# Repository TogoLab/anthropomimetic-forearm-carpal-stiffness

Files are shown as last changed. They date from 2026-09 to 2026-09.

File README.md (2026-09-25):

# Anthropomimetic Soft Robotic Forearm with Independently Articulated Carpal Bones

🌍 English (this page)  
📘 [Japanese](./README_JP.md)

---

## Overview

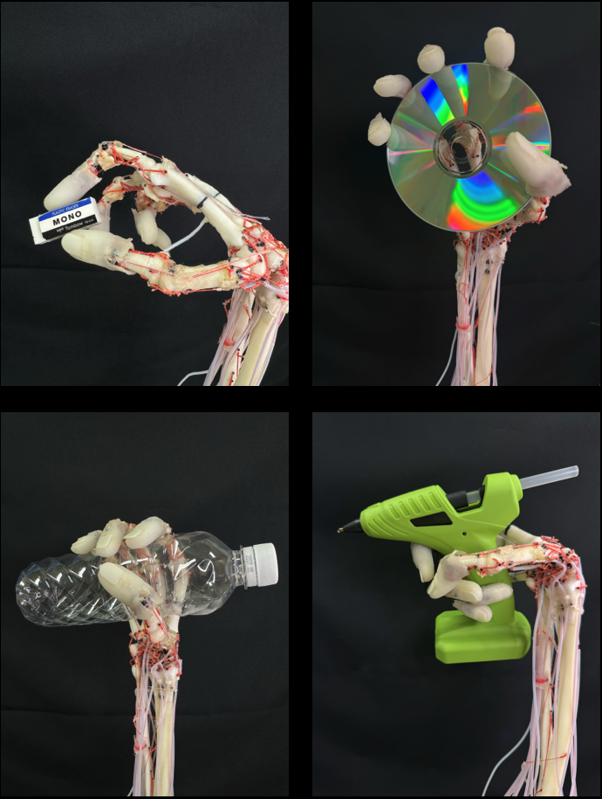
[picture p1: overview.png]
Anthropomimetic Soft Robotic Forearm


This repository provides open-hardware data for an **anatomically accurate anthropomimetic soft robotic forearm** composed of eight independently movable carpal bones interconnected by ligaments, 22 actuated muscles, and compliant fingertips, together with the CAD data of the assembly and experimental jigs, the muscle control firmware, and the wrist-stiffness / carpal-motion analysis code. The purpose of this repository is to improve the reproducibility of the following paper.

Yoshinobu Obata, Yinlai Jiang, Hiroshi Yokoi, and Shunta Togo.  
“Anthropomimetic Soft Robotic Forearm with Independently Articulated Carpal Bones Enabling Human-Like Adaptive Stiffness Modulability.”  
arXiv:2609.29176 [cs.RO], 2026.  
https://doi.org/10.48550/arXiv.2609.29176

---

## Repository Structure

```
analysis/   Wrist stiffness ellipse fitting and carpal motion analysis code with measured data, Python
firmware/   Muscle (Dynamixel) control firmware for the robotic forearm, PlatformIO
cad/        CAD files of the forearm and the experimental/assembly jigs (STEP, F3D)
stl/        STL files for 3D printing (bones, fingertip molds, TFCC, motor tower and pulleys, assembly and experimental jigs)
media/      Supplementary video
licenses/   Full text of the applicable licenses (CC BY 4.0, CC BY-SA 2.1 JP)
```

---

## Bill of Materials (BOM)

- [Bill of Materials (BOM)](./BOM.md)

---

## License

Multiple licenses apply to different parts of this repository.  
The bone models and fingertip molds are derived from **BodyParts3D** (Life Science Integrated Database Center) and are distributed under **CC BY-SA 2.1 JP**; all other materials are original works by the authors and are distributed under **CC BY 4.0**.  
Please make sure to check the license associated with each file before use.  
For details, see `LICENSE.txt` and the contents of the `licenses/` directory.

---

## Notes and Disclaimer

- This data is provided for educational and research purposes.
- Use, modification, and redistribution are performed at your own risk.
- The authors and affiliated institutions assume no responsibility for any damage or loss resulting from the use of this repository.

---

## Author and Contact

Shunta Togo  
Associate Professor  
Department of Mechanical and Intelligent Systems Engineering  
Graduate School of Informatics and Engineering  
The University of Electro-Communications  

- [ResearchMap](https://researchmap.jp/shuntatogo?lang=en)  
- [Togo Laboratory](http://www.hi.mce.uec.ac.jp/togolab/)  
- [X (Twitter)](https://twitter.com/togo_lab/)  
- [Instagram](https://www.instagram.com/togolab_uec/)  
- [YouTube](https://www.youtube.com/channel/UC10spcvW8-pCTLKy5rrDHyw)

For questions or bug reports, please use GitHub Issues or contact:  
s.togo[at]uec.ac.jp

Support for educational and research activities at the Togo Laboratory is also welcome.  
- https://www.uec.ac.jp/kikin/archives/fund/togolab

---

## Related Publications

* Yoshinobu Obata, Yinlai Jiang, Hiroshi Yokoi and Shunta Togo, "Design of anthropomimetic robotic wrist joint and forearm," 2023 IEEE International Conference on Systems, Man, and Cybernetics (SMC), pp. 1766–1771, Oahu, Hawaii, USA, Oct. 1–4, 2023.

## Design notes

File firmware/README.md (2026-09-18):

# 人体模倣前腕ロボットの制御システム

DynamixelサーボモーターとTeensy 4.1マイクロコントローラーを使用した22アクチュエーター人体模倣前腕ロボットの包括的制御システム。

## 概要

このプロジェクトは、人間の手と前腕の筋肉構造を模倣した前腕ロボットの高度な制御システムを実装しています。システムは22個の個別のDynamixelサーボモーターを制御し、それぞれが異なる筋肉を表現し、位置制御、電流制御、ハイブリッド電流ベース位置制御など、さまざまな動作モードをサポートしています。

## 必要なハードウェア

### マイクロコントローラー
- **Teensy 4.1**（SDIOと十分なI/Oのために必要）

### サーボモーター
- **22個のDynamixelサーボモーター**（プロトコル2.0対応）
- Dynamixel通信インターフェース（Serial2、ピン7-8）
- 方向制御ピン（ピン2）

### ストレージ
- **SDカード**（Teensy 4.1内蔵SDIOを使用）

### 追加コンポーネント
- 力量計センサー（アナログピンA16）
- 外部同期信号入力（ピンA17）
- PWMサーボ出力（ピン9）補助アクチュエーター用
- シリアルディスプレイとデバッグインターフェース

## ソフトウェア依存関係

### PlatformIOライブラリ
- `robotis-git/Dynamixel2Arduino@^0.6.3`
- `TeensyThreads`（マルチスレッド用）
- `SdFat`（SDカード操作）
- `Servo`（PWMサーボ制御）

## プロジェクト構造

```
├── src/
│   ├── main.cpp           # メインプログラムループとコマンドインターフェース
│   ├── contorol.h         # コアモーター制御機能
│   ├── DXLSetup.h         # Dynamixel設定と通信
│   ├── muscle.h           # 筋肉オブジェクト定義と管理
│   ├── motion.h           # モーション制御アルゴリズム
│   ├── coop_graph.h       # 協調筋グラフ（手首⇔指/屈伸の伝播）
│   ├── SDContorol.h       # SDカードデータ管理
│   ├── tests.h            # テストと校正機能
│   ├── teaching.h         # 教示モード（ユーザが手動で姿勢を作り SDに記録）
│   ├── config.h           # タイミング・ピン・サーボ数などのコンパイル時定数
│   ├── muscle_specs.h     # 筋ごとの静的属性（電流リミット・姿勢・可動域）テーブル
│   └── logging.h          # CSVヘッダー出力などのロギング補助
├── platformio.ini         # PlatformIO設定
└── README.md              # このファイル
```

## 筋肉マッピング

システムは以下の筋肉を表現する22個のサーボモーターを制御します：

### 指筋肉（0-14）
- **IndexFDP**（0）：示指深指屈筋
- **MiddleFDP**（1）：中指深指屈筋
- **MiddleFDS**（2）：中指浅指屈筋
- **RingFDP**（3）：薬指深指屈筋
- **PinkyFDP**（4）：小指深指屈筋
- **FPL**（5）：長母指屈筋
- **APM**（6）：母指内転筋（無限巻取り機構）
- **OPM**（7）：母指対立筋
- **APB**（8）：短母指外転筋
- **EIP**（9）：示指伸筋
- **EDM**（10）：小指伸筋
- **ED**（11）：総指伸筋
- **EPB**（12）：短母指伸筋
- **EPL**（13）：長母指伸筋
- **APL**（14）：長母指外転筋

### 手首筋肉（15-21）
- **FCR**（15）：橈側手根屈筋
- **FCU**（16）：尺側手根屈筋
- **ECRL**（17）：長橈側手根伸筋
- **ECU**（18）：尺側手根伸筋
- **SPN**（19）：回外筋（無限巻取り機構）
- **BPB**（20）：上腕二頭筋
- **PT**（21）：円回内筋

## 制御モード

### 1. 電流ベース位置制御（デフォルト）
- 位置制御と電流制御を組み合わせ
- 位置目標を持つコンプライアントモーションを可能にする

### 2. 純粋電流制御
- 直接電流・トルク制御
- 共収縮と剛性制御に使用

### 3. 位置制御
- 従来の位置のみ制御
- 精密な位置決めに使用

## 使用方法

### 初期設定

1. **ファームウェアの書き込み：**
   ```bash
   pio run --target upload
   ```

2. **シリアルモニターに接続：**
   ```bash
   pio device monitor
   ```

3. **システムの初期化：**
   - システムは自動的にDynamixel通信を初期化
   - モーション保存用のSDカードが初期化される

### 利用可能なコマンド

#### 教示モード
```
Teach
```
- 新しいモーションを記録する教示モードに入る
- 手を手動で位置決めし、ウェイポイントを保存
- 無限巻取り機構の使用をサポート（y/nプロンプト）

#### モーション再生
```
Start
```
- SDカードから記録されたモーションを再生
- 反復回数を選択
- モーションタイプを選択（1: リラックス、2: 把握）

#### システム制御
```
Relax    # 全モーターのトルクを無効化
Fix      # 低電流保持を有効化
Show     # 現在のサーボ位置を表示
```

#### ファイル管理
```
ls       # SDカード上のファイル一覧表示
Delete   # 保存されたモーションファイルを削除
```

#### テストと校正
```
Static   # 関節剛性テスト（4モード）
Random   # ランダム筋肉活動テスト
Unit     # 個別筋肉ユニットテスト
FingerDrive  # 個別指駆動テスト
```

#### マニュアル制御
```
Manual   # マニュアル位置入力（22個のカンマ区切り値）
servo    # 補助PWMサーボテスト（0-100%）
```

### モーションタイプ

#### 把握モーション
- 協調制御により指屈筋を活性化
- 安定した把握のための共収縮を実装
- 筋肉群に基づく電流制限の調整

#### リラックスモーション
- 筋肉の緊張を適切に軽減
- 最小限の保持電流を維持
- エネルギー効率を優先

## 設定

### 電流制限（mA単位）
- **指屈筋：** 筋肉により20-100mA
- **指伸筋：** 筋肉により20-400mA
- **手首筋肉：** 300mA
- **前腕筋肉：** 60-200mA

### 位置制限
- `muscle_specs.h`のテーブルで筋肉ごとに前進・後進限界を定義
- 安全制限により機械的損傷を防止

### タイミングパラメータ
- **サンプリング周期：** 10ms（100Hz）
- **デフォルトモーション時間：** 5秒
- **通信タイムアウト：** 10ms

## 安全機能

- **位置制限：** ハードウェア制限により過伸展を防止
- **電流制限：** モーター損傷と過熱を防止
- **タイムアウト保護：** 通信障害検出
- **トルク無効化：** 緊急停止機能

## データログ

システムはCSV形式でモーションデータをログ記録：
- タイムスタンプ
- 全22モーターの電流読取り値
- 全22モーターの位置読取り値
- オプションの力量計データ

## トラブルシューティング

### よくある問題

1. **Dynamixel通信障害：**
   - 配線とボーレート（1Mbps）を確認
   - サーボIDが連続的に0-21であることを確認
   - プロトコルバージョン（2.0）を確認

2. **SDカードエラー：**
   - SDカードが適切にフォーマットされていることを確認（FAT32）
   - Teensy 4.1のSDIO接続を確認

3. **モーションが不安定またはがたつく：**
   - 筋肉初期化の電流制限を調整
   - 干渉の位置制限を確認
   - 機械的組み立てを確認

### デバッグ出力
システムは`DEBUG_SERIAL`（SerialUSB）を通じて包括的なシリアルデバッグを提供。トラブルシューティングのため詳細出力を有効化してください。

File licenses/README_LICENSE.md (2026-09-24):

# License Guide

This repository is composed of materials distributed under multiple licenses.  
Please make sure to check the license applicable to each file or directory before use.

## Bone (Human Anatomy) Models and Fingertip Molds
- Scope: `cad/bone_*`, `stl/bone_*`, `cad/mold_*`, `stl/mold_*`
- License: Creative Commons Attribution-ShareAlike 2.1 Japan (CC BY-SA 2.1 JP)
- Original data source: BodyParts3D / Life Science Integrated Database Center, https://lifesciencedb.jp/bp3d/
- Notes:
   - Attribution is required (e.g., cite the paper and/or include this repository URL).
   - Any modified or redistributed versions must be released under the same license (share-alike).
   - This scope covers all three skeletal configurations used in the paper — the anatomically normal carpal bones, the fused proximal row (`bone_fixed_carpal_*`), and the geometric ellipsoidal skeleton (`bone_ellipsoidal_carpal_*`) — because each of them incorporates BodyParts3D-derived geometry.
   - The fingertip molds (`mold_*`) are shaped around the BodyParts3D-derived distal phalanges and are therefore covered by the same license.

## Original Design Parts (Motor Tower and Pulleys, Soft Tissue, Jigs)
- Scope: `cad/tower_*`, `cad/soft_tissue_*`, `cad/jig_*`, `cad/exp_*`, and the corresponding files under `stl/`
- License: Creative Commons Attribution 4.0 International (CC BY 4.0)
- Notes:
   - Attribution is required (e.g., cite the paper and/or include this repository URL).
   - Modification and commercial use are permitted.

## Control Firmware
- Scope: `firmware/*`
- License: Creative Commons Attribution 4.0 International (CC BY 4.0)
- Notes:
   - Attribution is required (e.g., cite the paper and/or include this repository URL).

## Experimental Data and Analysis Code
- Scope: `analysis/*`
- License: Creative Commons Attribution 4.0 International (CC BY 4.0)
- Notes:
   - Attribution is required (e.g., cite the paper and/or include this repository URL).

## Video (media)
- Scope: `media/*`
- License: Creative Commons Attribution 4.0 International (CC BY 4.0)
- Notes:
   - Attribution is required (e.g., cite the paper and/or include this repository URL).

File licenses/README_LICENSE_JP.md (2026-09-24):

# License Guide (日本語)

本リポジトリは、複数のライセンスを組み合わせて構成されています。
使用する際は、対象ファイルに適用されるライセンスを必ず確認してください。

## 骨（人体）モデル・指先モールド
- 対象: `cad/bone_*` , `stl/bone_*` , `cad/mold_*` , `stl/mold_*`
- ライセンス: Creative Commons Attribution-ShareAlike 2.1 Japan (CC BY-SA 2.1 JP)
- 原データ出典: BodyParts3D／ライフサイエンス統合データベースセンター, https://lifesciencedb.jp/bp3d/
- 注意:
   - クレジット表示が必要です（例: 論文の引用または本リポジトリURL）
   - 改変・再配布時は同一ライセンス（継承）が必要です
   - 論文で用いた3種の骨格構成——解剖学的に正常な手根骨、近位手根骨列を融合したもの（`bone_fixed_carpal_*`）、幾何学的楕円体骨格（`bone_ellipsoidal_carpal_*`）——はいずれもBodyParts3D由来の形状を含むため、すべて本節の対象です
   - 指先モールド（`mold_*`）はBodyParts3D由来の末節骨形状に沿って設計されているため、同じライセンスの対象です

## オリジナル設計部品（モータタワー・プーリ・軟部組織・治具）
- 対象: `cad/tower_*` , `cad/soft_tissue_*` , `cad/jig_*` , `cad/exp_*` および `stl/` の対応ファイル
- ライセンス: Creative Commons Attribution 4.0 International (CC BY 4.0)
- 注意:
   - クレジット表示が必要です（例: 論文の引用または本リポジトリURL）
   - 改変・商用利用も可能です

## 制御ファームウェア
- 対象: `firmware/*`
- ライセンス: Creative Commons Attribution 4.0 International (CC BY 4.0)
- 注意:
   - クレジット表示が必要です（例: 論文の引用または本リポジトリURL）

## 実験データ・解析コード
- 対象: `analysis/*`
- ライセンス: Creative Commons Attribution 4.0 International (CC BY 4.0)
- 注意:
   - クレジット表示が必要です（例: 論文の引用または本リポジトリURL）

## 動画（media）
- 対象: `media/*`
- ライセンス: Creative Commons Attribution 4.0 International (CC BY 4.0)
- 注意:
   - クレジット表示が必要です（例: 論文の引用または本リポジトリURL）

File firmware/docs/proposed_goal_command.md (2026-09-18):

# Firmware patch: `Goal` command for host scripting

Status: **APPLIED to source (`unit_test/src/main.cpp`), not yet flashed
to Teensy.** Required by the sim2real `run_static_handoff.py` runner
once we move out of `--dry-run`. Flash via `pio run -t upload` from
the `unit_test/` directory.

## Why

The current Teensy command set is interactive (`Teach`, `Start`,
`Static`, ...) — they prompt the user, then wait for a `readStringUntil`
on each step. That's fine for hands-on testing, but it means the host
PC cannot drive the rig from a script: there is no single-line "set
all 22 goal positions and acknowledge" command.

`cmdManual` looks like it should fill this role, but
[main.cpp:119-135](../src/main.cpp) shows that it parses the 22 CSV
ints from serial and never calls `sweepRunGoalPosition` — the parsed
`target[]` falls out of scope and the motors don't move.

## Protocol (two-line, matches existing handler idiom)

Host -> Teensy:

```
Goal\n
1234,5678,1024,...,2048\n     (22 ints, comma-separated)
```

Teensy -> host:

```
OK\n            (success: motors are being driven)
ERR:<reason>\n  (parse error or wrong count)
```

No interactive prompts. The two-line form matches how `cmdManual`,
`cmdDirection`, `cmdFingerDrive` already parse their inputs, so the
dispatch loop in `main.cpp:loop()` does not need to change.

## Patch

Append to `unit_test/src/main.cpp`:

```cpp
static void cmdGoal(){
  // Read the rest of the line after "Goal" -- expects ":1234,5678,...\n"
  String input = DEBUG_SERIAL.readStringUntil('\n');
  input.trim();
  int colon = input.indexOf(':');
  String csv = (colon >= 0) ? input.substring(colon + 1) : input;

  char buf[256];
  csv.toCharArray(buf, sizeof(buf));
  char* token = strtok(buf, ",");
  int32_t target[SERVO_NUM] = {};
  int8_t  torque_control_flags[SERVO_NUM] = {};
  int32_t e_angles[SERVO_NUM] = {};
  int count = 0;
  while (token != NULL && count < SERVO_NUM) {
    target[count++] = atoi(token);
    token = strtok(NULL, ",");
  }
  if (count != SERVO_NUM) {
    DEBUG_SERIAL.print("ERR:expected ");
    DEBUG_SERIAL.print(SERVO_NUM);
    DEBUG_SERIAL.print(" ints, got ");
    DEBUG_SERIAL.println(count);
    return;
  }
  sweepRunGoalPosition(target, e_angles, torque_control_flags,
                        MOVING_TIME, millis());
  DEBUG_SERIAL.println("OK");
}
```

And add to the `COMMANDS[]` array near line 213:

```cpp
{"Goal",        cmdGoal},
```

## Host-side expectation

`sim2real/dxl_host.py:send_goals` already implements the two-line
protocol:

```python
self._write_line("Goal")
self._write_line(",".join(str(x) for x in ints))
ack = self._wait_for_ack("OK")
```

The colon prefix removal in `cmdGoal` above tolerates either `Goal\nN,N,..\n`
or `Goal\n:N,N,..\n` (defensive against a future single-line variant).

## Testing plan after flashing

1. `python -m sim2real.dxl_host --port COMx --action show` — confirm
   existing `Show` still parses (regression check).
2. `python -m sim2real.dxl_host --port COMx --action test-goal` —
   sends all 22 motors to mid-range (2048); look for synchronised
   motion and `OK` ack.
3. `python -m sim2real.run_static_handoff --hold rest --port COMx` —
   smallest realistic move.
4. Withdrawal: if `OK` is not printed within 2 s, or if motors keep
   moving after `Relax`, do NOT proceed to keyframe sequences. Revert
   the firmware and investigate.

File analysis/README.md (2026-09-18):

# Wrist Stiffness & Carpal Motion — Experimental Data and Analysis Code

Experimental data and analysis programs for the figures reported in the paper on
adaptive wrist stiffness modulation of a tendon-driven musculoskeletal hand.

Everything here is a verbatim copy of the working repository, restricted to the
data and code actually used for the published figures. Source files are
unmodified; console output and inline comments are in Japanese.

---

## 1. Contents

```
analysis/
├── README.md
├── requirements.txt
│
├── stiffness_ellipse/                   # Wrist stiffness ellipse experiment
│   ├── all_ellipse_fitting_stiffnes.py  #   main program
│   ├── lib/
│   │   ├── analyze.py                   #   force/displacement -> stiffness per push direction
│   │   ├── fitting.py                   #   least-squares ellipse fit (Cartesian form)
│   │   └── utils.py                      #   measurement angles, CSV column layout
│   ├── direction_ellipse_rotation_repo.py        # STATS: permutation test (paper result)
│   ├── direction_anova_finger_vs_combined.py     # STATS: two-way ANOVA + long-data builder
│   ├── direction_harmonic_finger_vs_combined.py  # STATS: harmonic nested-F test
│   ├── direction_statistics_methods.md           # STATS: methods write-up (Japanese)
│   ├── datas/
│   │   ├── normal/0202/                  #   (1) Normal skeleton
│   │   ├── fixed_bone/0220/              #   (2) Fused proximal row
│   │   └── ellipse_carpal/0223/          #   (3) Geometric ellipsoidal skeleton
│   ├── results/
│   │   ├── direction_anova_long_data.csv #   cached per-trial stiffness (input to the stats)
│   │   └── ellipse/                      #   output (empty; created on run)
│   └── pngs/force_distance/              #   per-trial debug plots (middle_plot=True)
│
├── carpal_motion/                       # Intra-carpal motion experiment
│   ├── main_publication_figures.py       #   main program (figures for the paper)
│   ├── main_with_stiffness.py            #   analysis pipeline it drives
│   ├── lib/carpal_analysis/              #   loaders, angle/translation/stiffness analysis
│   │   └── publication_bar_charts.py     #   STATS: one-way ANOVA + Tukey HSD, plotting
│   ├── datas/carpal_motion/20250803/     #   measurement session used in the paper
│   └── pngs/                             #   output (empty; created on run)
│
└── figures_in_paper/                    # reference outputs, for comparison
    ├── result_normal.png
    ├── result_fixed_carpal.png
    ├── result_ellipsoidal_carpal.png
    ├── carpal_relative_rotation.png
    ├── carpal_relative_translational_motion.png
    ├── wrist_stiffness.png
    └── fullres_ellipse/                  #   full-resolution PNG/SVG of the ellipse plots
```

Total size ≈ 194 MB (2,424 CSV files).

## 2. Setup

```bash
python3 -m venv venv
source venv/bin/activate
pip install -r requirements.txt
```

`japanize-matplotlib` is required only because the plotting helpers import it;
it does not affect the English figure labels.

---

## 3. Experiment 1 — Wrist stiffness ellipse

The hand was pushed by a force gauge from 12 directions in the transverse plane
(0°–330°, every 30°) under four muscle activation conditions. Stiffness per
direction is estimated from the force–displacement slope, and an ellipse is
fitted to the resulting polar stiffness profile.

### Run

```bash
cd stiffness_ellipse
python all_ellipse_fitting_stiffnes.py
```

The skeleton type is selected by the `data_dir` variable at
[all_ellipse_fitting_stiffnes.py:17-19](stiffness_ellipse/all_ellipse_fitting_stiffnes.py#L17-L19).
Uncomment the one you want:

| `data_dir` | Skeleton | Paper figure |
| --- | --- | --- |
| `./datas/normal/0202/` | Normal (8 mobile carpal bones) | `result_normal.png` |
| `./datas/fixed_bone/0220/` | Fused proximal row | `result_fixed_carpal.png` |
| `./datas/ellipse_carpal/0223/`| Geometric ellipsoidal skeleton | `result_ellipsoidal_carpal.png`|

Analysis parameters are identical for all three skeletons:
`start_force = [0.15, 0.2, 0.6, 0.7]` N (per condition, in the order
low / high / finger / super_high) and `measurement_distance = 3` mm.

### Output

- `results/ellipse/ellipse_cartesian_<skeleton>.png` / `.svg` — the fitted ellipses
- `results/ellipse/mean_and_std/<skeleton>_<condition>.png` — mean ± SD bar chart per direction
- `results/ellipse/param/<skeleton>_error_files.txt` — trials rejected by contact detection
- `pngs/force_distance/…` — per-trial force–displacement plots (`middle_plot=True`; ~2,300 PNGs, a few hundred MB)

The script ends with an interactive `plt.show(block=True)` using the `TkAgg`
backend. The figures in the paper were captured from that window, which is why
the axis range there is ±300 N/m rather than the ±600 N/m of the saved PNG; the
ellipses themselves are identical. On a headless machine, change
`matplotlib.use('TkAgg')` on line 5 to `matplotlib.use('Agg')` and the saved
files are still produced.

### Conditions

| Directory | Label in figures | Activation |
| --- | --- | --- |
| `low_contraction` | Relax | no activation |
| `high_contraction` | Wrist Muscle | wrist muscles only |
| `finger_contraction` | Finger Muscle | finger muscles only |
| `super_high_contraction`| Wrist and Finger Muscles  | wrist + finger muscles |

Each condition holds `force_gage/` and `motion_capture/`, 8 trials × 12
directions (`push_<angle>_deg_<trial>.csv` and `Push_<angle>_deg_<nnn>.csv`).

---

## 4. Experiment 2 — Intra-carpal motion

Optical markers on the radius, lunate, scaphoid and capitate were tracked while
the wrist was pushed, under three activation conditions. Scaphoid and capitate
motion is expressed relative to the lunate frame.

### Run

```bash
cd carpal_motion
python main_publication_figures.py
```

No arguments; the measurement session is fixed to `datas/carpal_motion/20250803/`
at [main_with_stiffness.py:648-661](carpal_motion/main_with_stiffness.py#L648-L661).
Runtime is a few minutes.

### Output

| File | Paper figure |
| --- | --- |
| `pngs/relative_rotation.png`| `carpal_relative_rotation.png` |
| `pngs/relative_translational.png` | `carpal_relative_translational_motion.png` |
| `pngs/wrist_joint_stiffness.png`  | `wrist_stiffness.png` |

These three reproduce byte-for-byte (verified by MD5) against the copies in
`figures_in_paper/`. One-way ANOVA and Tukey HSD (`scipy.stats.tukey_hsd`) are
computed and annotated on each panel; the test statistics are printed to stdout.

### Conditions

| Directory | Label in figures | Files |
| --- | --- | --- |
| `wrist_contraction` | Wrist muscles | `Wrist_*.csv` |
| `finger_contraction` | Finger muscles | `Finger_*.csv` |
| `finger_wrist_contraction` | Combined activation  | `FingerWrist_*.csv` |

20 trials per condition, in `force_gage/` and `motion_capture/`.

---

## 5. Statistical tests

Two statistical results are reported in the paper, produced by two different
programs.

### 5.1 Ellipse reorientation — stratified permutation test

*Section "Analysis Method"; Results: "Δθ_max = 48.2°, exceeded all but 18 of
5000 label-shuffled null rotations (p = 0.0038)".*

```bash
cd stiffness_ellipse
MPLBACKEND=Agg python direction_ellipse_rotation_repo.py
```

Tests whether the maximum-stiffness direction θ_max of the normal skeleton
really differs between finger-muscle and combined activation, or whether the
shift is trial-to-trial noise. Per-trial stiffness values are pooled across the
two conditions and the condition label is shuffled **within each of the 12
loading directions** (5000 times, `SEED = 20250620`), refitting the ellipse with
the same `lib.fitting.fit_cartesian` used for the paper figures and recomputing
the circular difference in θ_max each time. Trials below 5 N/m are dropped, as
in the main analysis. A bootstrap 95 % CI (3000 resamples) is also printed.

Expected output — reproduced exactly on a fresh run:

```
Finger   : max-stiffness angle =  254.0 deg, min-stiffness angle =  151.7 deg
Combined : max-stiffness angle =  302.2 deg, min-stiffness angle =  197.9 deg
Observed rotation: Δmax = 48.2 deg, Δmin = 46.3 deg
[Permutation] p(Δmax >= observed) = 0.003799  (null median 16.6, 95th 37.5 deg)
[Bootstrap]   Δmax = 48.2 deg, 95% CI [23.8, 176.3]
```

The four angles match the normal-skeleton rows of Table "Stiffness ellipse
parameters for normal skeleton" (finger and combined conditions). p = 0.003799
is (18 + 1) / (5000 + 1), reported as p = 0.0038.

Outputs `results/direction_ellipse_rotation_repo.png` (the two ellipses with
their max-stiffness directions), `results/direction_ellipse_rotation_nulldist.png`
(the null distribution) and the matching `.npz` cache; rerunning with
`--replot` redraws the null-distribution figure from that cache.

Input is `results/direction_anova_long_data.csv` — per-trial stiffness in long
format (`stiffness, condition, angle, rep`), shipped here so the test runs in
about a minute. To rebuild it from the raw CSVs instead (slow), run
`direction_anova_finger_vs_combined.py`, which writes the same file.

### 5.2 Carpal motion — one-way ANOVA + Tukey HSD

*Results: "F = 6.69, p = 0.0025" for wrist joint stiffness, "F = 3.89,
p = 0.026" and "F = 5.92, p = 0.0046" for proximal row relative rotation and
translation, with the Tukey HSD pairwise p-values.*

These are computed inside
[publication_bar_charts.py](carpal_motion/lib/carpal_analysis/publication_bar_charts.py)
(`scipy.stats.f_oneway` and `scipy.stats.tukey_hsd`) and annotated directly onto
the bars, so they come out of the `main_publication_figures.py` run in Section 4;
the statistics are also printed to stdout:

```
[Wrist joint stiffness] 1-way ANOVA: F=6.694, p=0.002447
    Tukey Wrist muscles vs Combined activation: p=0.001632  *
[Relative rotation [deg] / Scafoid] 1-way ANOVA: F=3.886, p=0.02619
[Relative translational [mm] / Scafoid] 1-way ANOVA: F=5.918, p=0.004621
```

### 5.3 Supporting tests (not reported in the paper)

[direction_statistics_methods.md](stiffness_ellipse/direction_statistics_methods.md)
documents the three direction tests that were run during the analysis, of which
only the third became the reported result. The other two are included here for
completeness:

| Script | Test | Status |
| --- | ---- | --- |
| `direction_anova_finger_vs_combined.py` | Two-way ANOVA, condition × angle interaction (Type II SS, scale-normalized) | not reported; also builds the cached long-format CSV |
| `direction_harmonic_finger_vs_combined.py` | Harmonic (circular) model, nested F test on the 1st/2nd order terms | not reported |
| `direction_ellipse_rotation_repo.py` | Stratified permutation test on Δθ_max | **reported (Section 5.1)** |

Both supporting scripts require `statsmodels`; the reported permutation test
does not.

---

## 6. Data formats

### `motion_capture/*.csv` — OptiTrack Motive export

Standard Motive CSV, version 1.24. 100 Hz, millimetres, quaternion rotation.
Rows 1–7 are the header block (take metadata, rigid-body names, IDs, the
Rotation/Position channel labels, and the column names
`Frame, Time (Seconds), X, Y, Z, W, X, Y, Z, …` repeating per rigid body);
measurement rows start at row 8.

- Experiment 1: a single rigid body on the hand.
- Experiment 2: `Lunate`, `Scafoid`, `ForceGage`, `Radius`, `Capitate`.
  (`Scafoid` is the spelling used throughout the code and the raw data.)

### `force_gage/*.csv` — motor state and force gauge, no header row

46 columns, defined in [utils.py](stiffness_ellipse/lib/utils.py):

| Column | Meaning |
| --- | --- |
| 1 | `timestamp` [ms] |
| 2–45 | `curr1, pos1, curr2, pos2, … curr22, pos22` — current and position of the 22 tendon-driving motors |
| 46 | `Force` [N] — force gauge reading |

---

## 7. Notes for reuse

- Both programs use relative paths and must be run from their own directory
  (`stiffness_ellipse/` and `carpal_motion/` respectively).
- No absolute paths are embedded anywhere in the code.
- All CSV files are bit-identical to the originals used for the paper
  (verified by MD5 over all 2,424 files).
- Trials listed in `results/ellipse/param/*_error_files.txt` are automatically
  excluded by the contact-detection step in `lib/analyze.py`; they are still
  shipped here so the rejection can be re-examined.

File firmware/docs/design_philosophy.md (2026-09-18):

# 設計思想: 手首優位の協調筋制御による把持

## 課題

センサレスロボットハンドで物体を把持するため、完全に指を屈曲させ握りこぶしを作った状態のサーボ角度位置を目標角度とし、物体を把持させる方法を取っている。握りこぶしの状態では指伸筋腱が伸びきった状態で固定される。物体を把持した状態では指関節角度が小さくなり、指伸筋腱が完全に緩み、背屈ができない状態になる。手首が物理的に固定されているロボットアームではこのような問題は起こらない。

解決策としては、腱にバネなどの弾性体を繋げ張力を一定に保つ方法、屈曲側と伸筋側のサーボ回転角度を把持物体に合わせて調節する方法などがある。

## 解決方法

本研究では、機械的アプローチを取らず、**筋肉同士の協調動作**をソフトウェアで実装する。手首を優位として、指の筋肉を連動させる。

- 緊張する指の筋はトルクが能動的に与えられる（トルク制御）
- 弛緩する筋は低トルク（電流位置制御モード）
- 把持時、伸筋側は受動的な腱の伸長が起こると仮定
- 緊張する筋 → トルク制御、弛緩する筋 → 電流位置制御

## 協調ルール

### 手首筋から指筋への伝播（直接協調）

| 手首筋が緊張 | 協調して駆動される指筋 |
|---|---|
| FCR（橈側手根屈筋） | IndexFDP + FPL |
| FCU（尺側手根屈筋） | PinkyFDP |
| ECRL（長橈側手根伸筋） | EIP |
| ECU（尺側手根伸筋） | EDM |

これがコードの `setWristCoopFlags` に対応する。

### 伸筋ノード（背屈時のみ緊張）

```
EIP AND EDM が緊張 → ED + FPL もトルク制御で緊張
```

FPL（長母指屈筋）が背屈時の指伸筋群と協調するのは、指背屈時に母指を屈曲させて指の背側に母指を重ねる動作（握り拳を作る際の自然な母指位置）のため。

### 屈筋ノード（掌屈時のみ緊張）

```
IndexFDP AND PinkyFDP が緊張 → MiddleFDP + RingFDP もトルク制御で緊張
```

示指と小指の深指屈筋が両方緊張したとき、中指と薬指の屈筋も波及的に緊張する。

これがコードの `propagateCoopFlags` に対応する。

## コード実装

- `setWristCoopFlags(ID, flags)`: 手首筋 ID が与えられたとき対応する指筋フラグを立てる
- `applyGraspCurrent(ID)`: 協調フラグが立っていない筋に、筋種別の目標電流を割り当て
- `propagateCoopFlags(flags)`: 伸筋・屈筋ノードの AND 論理で MiddleFDP/RingFDP/ED/FPL に伝播
- `graspMotion` (`coopGraspMotion`): 上記を束ねて制御モードを決定

## 目標電流一覧（`DXLSetup.h`）

| 定数 | 値 | 用途 |
|---|---|---|
| `MAX_FLEX_CURRENT` | 20 | 4指深指屈筋の把持電流 |
| `THUMB_FLEX_CURRENT` | 30 | FPL（長母指屈筋）の把持電流。4指に対向するため少し高め |
| `MAX_EXTENS_CURRENT` | 20 | 指伸筋の把持電流 |
| `MAX_EXTENS_ED_CURRENT` | 40 | 総指伸筋 ED の CurrentLimit |
| `MIN_CURRENT` | 30 | 弛緩時の最小電流 |
| `GENERAL_CURRENT` | 100 | 母指系（APM/APB/OPM/EPB/EPL/APL）の位置制御電流 |
| `CARPAL_CURRENT` | 200 | 手首筋 FCR/FCU/ECRL/ECU の位置制御電流 |
| `SP_CURRENT` | 150 | BPB/PT |
| `PR_CURRENT` | 200 | PQ |
| `TEACHING_FINGER_CURRENT` | 30 | 教示モードの指の目標電流 |
| `TEACHING_WRIST_CURRENT` | 60 | 教示モードの手首関節の目標電流 |
| `TEACHING_FOREARM_CURRENT` | 60 | 教示モードの前腕関節の目標電流 |

## 再生フロー

1. 現在の各サーボ回転角度を取得
2. 目標回転角度を取得
3. 角度差からサーボ回転速度を算出
4. 緊張する筋の種類から制御手法決定（`coopGraspMotion` / `relaxMotion`）
5. サーボを回転
6. 100Hz 間隔で電流トルクを徐々に上昇（`sweepRunGoalPosition` 内のランプ）

## 参考: 手首動作別の協調パターン（PlantUML 図は別途）

- **背屈**: ECRL/ECU 緊張、FCR/FCU 弛緩。伸筋ノード発火 → ED + FPL 緊張
- **掌屈**: FCR/FCU 緊張、ECRL/ECU 弛緩。屈筋ノード発火 → Middle/Ring 緊張
- **撓屈**: ECRL/FCR 緊張、ECU/FCU 弛緩。FCR → FPL + IndexFDP、ECRL → EIP

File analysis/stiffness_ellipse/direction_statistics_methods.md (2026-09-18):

# 剛性の「方向（異方性の向き）」が条件間で異なるかの統計検定

Finger Muscle 条件と Wrist+Finger Muscles（Combined）条件で、剛性の**大きさ**ではなく
**方向（角度依存パターン／異方性楕円の向き）**が異なることを示すために行った 3 つの統計検定の
詳細をまとめる。

- 検定1: カテゴリ二元配置分散分析の交互作用（omnibus）
- 検定2: 調和（円周）モデルの入れ子 F 検定（1次／2次成分の分解）
- 検定3: 剛性楕円フィット＋最大剛性角の回転に対する並べ替え検定（**主結果候補**）

対応スクリプト:
- `direction_anova_finger_vs_combined.py` … 検定1
- `direction_harmonic_finger_vs_combined.py` … 検定2
- `direction_ellipse_rotation_repo.py` … 検定3

---

## 0. 共通のデータ基盤

- **観測単位**: 1 試行 = 1 つの剛性値 `stiffness`（`lib.analyze.calcurate_sttiffness` で算出）。
- **設計**: 2 条件 × 12 角度（0,30,…,330°）× 8 反復。有効試行のみ採用。
- **キャッシュ**: `results/direction_anova_long_data.csv`（列 `stiffness, condition, angle, rep`）。
  重い剛性再計算を避けるため検定2・3はこれを読み込む。
- **前処理（検定2・3）**: `stiffness < 5 N/mm` の生理的に非現実な外れ値（中央値≈82 に対し 0.40,
  0.46 の 2 件）を除外。除外有無で結論は不変であることを確認済み。
- 有効 n: 各条件 95 試行（フィルタ後）。

記号:
- $y$ : 剛性（または変換後の値）
- $\theta$ : 押下角度 [rad]、$\theta = \text{angle}\times\pi/180$
- 条件 $i\in\{\text{Finger},\text{Combined}\}$、角度 $j\in\{1,\dots,12\}$、反復 $k$

---

## 検定1: 二元配置分散分析の condition × angle 交互作用

**スクリプト**: `direction_anova_finger_vs_combined.py`

### 仮説
角度ごとの剛性プロファイル（角度依存パターン）が条件間で異なる
＝ 条件と角度の**交互作用**が存在する。

### モデル
角度を 12 水準の**カテゴリ変数**として二元配置 ANOVA を組む:

$$
y_{ijk} = \mu + \alpha_i + \beta_j + (\alpha\beta)_{ij} + \varepsilon_{ijk}
$$

- $\alpha_i$ : 条件主効果、$\beta_j$ : 角度主効果、$(\alpha\beta)_{ij}$ : **交互作用**（これが検定対象）。
- 大きさの差を除くため、各条件を自条件のグランド平均で割った正規化値
  $y^{\text{norm}}_{ijk} = y_{ijk}/\bar y_{i\cdot\cdot}$ を応答とした版も実施（条件主効果は構成上ほぼ消える）。

### 統計量
交互作用項の **F 値**:

$$
F = \frac{\text{MS}_{\text{interaction}}}{\text{MS}_{\text{error}}}
  = \frac{\text{SS}_{\text{interaction}} / \text{df}_{\text{interaction}}}{\text{SS}_{\text{error}} / \text{df}_{\text{error}}}
$$

- 分子（シグナル）: 加法モデルからの非加法ズレの二乗和。セルごとの交互作用成分
  $\widehat{(\alpha\beta)}_{ij} = \bar y_{ij\cdot} - \bar y_{i\cdot\cdot} - \bar y_{\cdot j\cdot} + \bar y_{\cdot\cdot\cdot}$
  を二乗して反復数で重み付けて合計したもの。
- 分母（ノイズ）: セル内の反復ばらつき（誤差分散）。
- $\text{df}_{\text{interaction}} = (2-1)(12-1) = 11$。

### 算出手順
1. ロングデータを構築（`build_long_data`）。
2. 正規化値を計算（`normalize`）。
3. `statsmodels` の式 `y ~ C(condition) * C(angle)` で OLS フィット。
4. `anova_lm(model, typ=2)` で **Type II 平方和**の ANOVA 表を取得。
   - Type II は交互作用項に関しては Type III と一致するため、交互作用の検定には妥当。
   - ただし主効果は交互作用がある状況では解釈しない（本検定では交互作用のみ報告）。
5. 交互作用行 `C(condition):C(angle)` の F と p を読む。
6. 同じ手順を生値 `stiffness` と正規化値 `stiffness_norm` の両方で実施。

### 結果
- 正規化版: **F(11, …) = 4.68, p = 3.2×10⁻⁶**（有意）
- log 変換版（頑健性確認）: F = 3.27, p = 4.5×10⁻⁴（有意）

### 解釈と限界
- 「角度プロファイルが**何らかの形で**異なる」ことを示す **omnibus 検定**。
- 1 つの角度での突出（大きさのブレ）でも有意になり得て、「異方性の向きが回転した」ことを
  特定はしない。→ そこを切り分けるのが検定2・3。
- 正規化（グランド平均除算）は大きさ除去のアドホックな方法。原理的には log 変換（乗法的な
  大きさ差を加法的な主効果に変換）が等価で望ましい。両方で有意なので結論は頑健。

---

## 検定2: 調和（円周）モデルの入れ子 F 検定

**スクリプト**: `direction_harmonic_finger_vs_combined.py`

### 動機
角度は円周変数（0–330°）なので、カテゴリ 11 自由度ではなく**調和項**で表すと
自由度が節約でき、かつ成分の物理的意味（非対称性 vs 異方性軸）が分離できる。

### モデル
$\log$ 剛性を条件 × 調和項で表す:

$$
\log K = \beta_0 + \alpha\,\mathbb{1}[\text{cond}] + \sum_{m=1}^{2}\bigl(b_{mc}\cos m\theta + b_{ms}\sin m\theta\bigr) + (\text{condition} \times \text{harmonics の交互作用})
$$

- **log スケール**: 条件間の乗法的な大きさ差を加法的な条件主効果 $\alpha$ に押し込めるので、
  **condition × 調和項の交互作用が「大きさに依存しない形（shape）」を表す**。
  → 検定1の正規化のようなアドホックな割り算が不要。
- 1次調和（$\cos\theta,\sin\theta$、360°周期）= 方向**非対称性**（片側だけ硬い）。
- 2次調和（$\cos 2\theta,\sin 2\theta$、180°周期）= 双方向の**異方性軸**（楕円の主軸に対応）。

### 統計量
追加した交互作用項に対する**入れ子モデルの F 検定**（部分 F 検定）:

$$
F = \frac{(\text{SSR}_{\text{reduced}} - \text{SSR}_{\text{full}}) / q}{\text{SSR}_{\text{full}} / (n - p_{\text{full}})}
$$

- $\text{SSR}$ : 残差平方和。reduced = 交互作用なし（加法）モデル、full = 交互作用ありモデル。
- $q$ : 追加した交互作用項の数（= 検定する自由度）。
- 直観: 「交互作用を入れたことで残差がどれだけ減ったか」をノイズで規格化したもの。

### 算出手順
1. キャッシュ読み込み → フィルタ → `theta`, `logK` と調和列 `h1c,h1s,h2c,h2s` を作成。
2. 3 種類の交互作用を入れ子比較（`anova_lm(reduced, full)`）:
   - **結合**: full に `condition:(h1c,h1s,h2c,h2s)`（$q=4$）
   - **1次**: full に `condition:(h1c,h1s)`（$q=2$）
   - **2次**: full に `condition:(h2c,h2s)`（$q=2$）
   - reduced は常に加法モデル `logK ~ C(condition) + h1c+h1s+h2c+h2s`。
3. 各条件を個別に $\log K \sim$ 調和でフィットし、幾何量を抽出:
   - 1次振幅 $A_1=\sqrt{b_{1c}^2+b_{1s}^2}$、ピーク方向 $\phi_1=\operatorname{atan2}(b_{1s},b_{1c})$
   - 2次軸 $\theta_{\text{axis}} = \tfrac12\operatorname{atan2}(b_{2s},b_{2c})\ (\bmod 180°)$

### 結果
| 交互作用 | 自由度 $q$ | F | p | 意味 |
|---|---|---|---|---|
| 結合（全調和） | 4 | 10.28 | 1.6×10⁻⁷ | 角度パターンが条件間で異なる |
| 1次調和 | 2 | 14.90 | 1.0×10⁻⁶ | **方向非対称性**が異なる |
| 2次調和（異方性軸） | 2 | 4.08 | 0.018 | **異方性軸の向き**が異なる |

幾何量（log フィット）: Finger 1次ピーク 293° / 2次軸 68°、Combined 1次ピーク 354° / 2次軸 104°。

### 解釈と限界
- 違いの主因は 1次成分（方向非対称性、p=10⁻⁶）で、2次成分（軸の回転、p=0.018）も有意。
- 2次成分だけでは「楕円の向き」だが、1次が大きいためプロファイルは純粋な楕円ではない。
  → 楕円の枠組みで明示的に扱うのが検定3。

---

## 検定3: 剛性楕円フィット＋最大剛性角の回転（並べ替え検定）

**スクリプト**: `direction_ellipse_rotation_repo.py`
**フィット法は論文・リポジトリと同一**（`lib.fitting.fit_cartesian`）。

### 仮説
剛性楕円の主軸（最大剛性方向）が条件間で**回転**している。大きさとは独立。

### 楕円フィット（論文の手法）
1. 各条件で角度ごとの**平均剛性** $\bar K_j$ を求める。
2. 極→直交変換 $x_j=\bar K_j\cos\theta_j,\ y_j=\bar K_j\sin\theta_j$。
3. `fit_cartesian(x,y)`: 点群から楕円までの**幾何距離の二乗和**を `L-BFGS-B` で最小化し、
   楕円パラメータ $(a,b,h,k,\phi)$ を得る（中心 $(h,k)$ はデータ重心に固定）。

   $$\min_{a,b,\phi}\ \sum_j\left[\left(\frac{x'_j}{a}\right)^2+\left(\frac{y'_j}{b}\right)^2-1\right]^2,\quad (x',y')=R(\phi)\,(x-h,\,y-k)$$
4. 楕円上を密にサンプルし、**原点からの距離** $\lVert(x_e,y_e)\rVert$ が最小／最大となる点の
   角度を求める:

   $$\theta_{\max} = \operatorname{atan2}(y_e^{\max}, x_e^{\max}),\qquad \theta_{\min} = \operatorname{atan2}(y_e^{\min}, x_e^{\min})$$

   これが論文で報告している**最小剛性角・最大剛性角**（`phis_min`/`phis_max`）。

### 統計量
2 条件の**最大剛性角の円周差**（楕円の硬い方向の回転量）:

$$
\Delta_{\max} = \text{circdiff}(\theta_{\max}^{\text{Finger}},\, \theta_{\max}^{\text{Combined}}),
\qquad \text{circdiff}(a,b)=\min\bigl(|a-b|\bmod 360,\ 360-|a-b|\bmod 360\bigr)\in[0,180]
$$

- **統計量が「角度」そのもの**なので、全体の大きさ（スケール）に不変。
  → 「大きさではなく向き」を定義上クリーンに検定できる。

### 検定1: 層別並べ替え検定（p 値）
帰無仮説「向きは条件に依らない」のもとでの $\Delta_{\max}$ の分布を、ラベル入れ替えで構成:

1. **各角度内で**条件ラベルをシャッフル（角度構造を保つ層別並べ替え）。
2. 擬似 Finger / 擬似 Combined それぞれで平均→楕円フィット→$\theta_{\max}$→$\Delta_{\max}^{(\text{perm})}$ を再計算。
3. 1–2 を $N=5000$ 回繰り返し、帰無分布を得る。
4. p 値 $= \dfrac{\#\{\Delta^{(\text{perm})} \ge \Delta^{\text{obs}}\}+1}{N+1}$。

### 検定2: ブートストラップ（信頼区間）
1. 各 (condition, angle) セル内で反復を**復元抽出**。
2. 平均→楕円フィット→$\theta_{\max}$→$\Delta_{\max}$ を再計算。
3. $N=3000$ 回繰り返し、$\Delta_{\max}$ の 2.5/97.5 パーセンタイルを 95% CI とする。

### 結果
| | 最大剛性角 | 最小剛性角 |
|---|---|---|
| Finger | 254.0° | 151.7° |
| Combined | 302.2° | 197.9° |

- 回転 **$\Delta_{\max}$ = 48.2°**（$\Delta_{\min}$ = 46.3° と整合）
- 並べ替え検定 **p = 0.0038**（帰無中央値 16.6°、95 パーセンタイル 37.5° に対し観測 48°）
- ブートストラップ 95% CI = [23.8°, 176.3°]

### 解釈と限界
- 最大剛性方向が約 48° 回転しており、並べ替え検定で **p = 0.0038** と強く有意。
- **ブートストラップ CI の上限が 176° と暴れる**: 原点オフセットのある楕円で、リサンプル時に
  楕円がほぼ円に近づくと $\theta_{\max}$ が ±180° 反転するため。角度差の対称 CI が不安定になるので、
  **p 値を主たる推定**とし、CI はブートストラップ分布が重裾である旨を添える。下限 24° が 0 から
  十分離れている点は強調できる。
- `fit_cartesian` 内の divide-by-zero 警告は退化楕円（$b\approx0$）が稀に出るためで結果に影響なし。

---

## 3 検定の比較

| | 検定1 ANOVA | 検定2 調和 | 検定3 楕円回転 |
|---|---|---|---|
| 統計量 | 交互作用の F | 入れ子 F（部分 F） | 最大剛性角の円周差 $\Delta_{\max}$ |
| 帰無分布 | F 分布（理論） | F 分布（理論） | 並べ替え（経験分布） |
| 角度の扱い | 12 水準カテゴリ | 調和（円周, 2次まで） | 楕円フィット（論文手法） |
| 大きさの除去 | グランド平均で正規化 | log 変換（加法主効果へ） | 角度統計量ゆえ自動的に不変 |
| 何を示すか | プロファイルが異なる（omnibus） | 非対称性／軸の分離 | 楕円主軸の回転 |
| 結果 | F=4.68, p=3×10⁻⁶ | 結合 p=2×10⁻⁷、軸 p=0.018 | 回転 48°, p=0.0038 |
| 論文との整合 | — | — | **フィット法が一致（主結果候補）** |

## 共通の注意点
- **`start_force` が条件間で異なる**（Finger 0.6 / Combined 0.7）。この閾値差が測定窓を系統的に
  ずらし、それ自体が交互作用・回転を生む可能性がある。同一閾値で剛性を再計算しても結果が
  保たれるか確認すると盤石。
- 検定1の混合モデル（`groups=rep`）は反復番号を疑似ブロックにしており、意味のある乱塊構造では
  ないため検定2・3では採用していない（実在のグルーピング＝被験者/セッションがあればそれを使う）。

---

# 付録A: 並べ替え検定（permutation test）の詳細

検定3の主たる推定に用いた並べ替え検定について、考え方・手順・前提・図を詳述する。

## A.1 一言で言うと

> **「条件ラベルをデタラメに貼り替えても、観測したのと同じくらい大きな回転が出るか？」を、
> 実際に何千回も試して確かめる検定。**

もし「Finger と Combined で楕円の向きは本当は変わらない」のなら、どの試行がどちらの条件かという
**ラベルには意味がない**はず。ならばラベルをランダムに入れ替えても、回転角はたまたま似た値に
なるはずである。実際に入れ替えを繰り返して「ラベルが無意味なときの回転角の分布（＝帰無分布）」を
作り、観測した 48° がその中でどれだけ珍しいかを数える。

## A.2 なぜこの検定を選んだか

- **統計量が「角度（回転量）」**で、その理論的な標本分布が分からない。t/F のような既成の分布を
  当てはめられないため、データ自身を並べ替えて分布を自前で構成する必要がある。
- **分布の正規性などの仮定を置かない**（ノンパラメトリック）。少数 n（各条件 95 試行、角度あたり
  7–8 反復）でも、仮定違反の心配なく p 値が得られる。
- 統計量が角度なので**全体の大きさ（スケール）に不変** → 「大きさではなく向き」を狙い撃ちできる。

## A.3 帰無仮説と交換可能性（exchangeability）

- **帰無仮説 $H_0$**: 剛性の角度プロファイル（ひいては楕円の向き）は条件ラベルに依存しない。
- $H_0$ のもとでは、**同じ角度で測った試行どうしは条件ラベルを入れ替えても確率的に等価**
  （exchangeable）。この交換可能性が並べ替えの妥当性の根拠。
- **層別（stratified）にする理由**: 角度そのものは強い効果を持つ（剛性は角度依存）。ラベルを全体で
  無差別にシャッフルすると、たまたま片方の擬似条件に特定の角度が偏り、角度効果が条件差に
  漏れ込む。これを防ぐため、**各角度の内側だけでラベルを入れ替える**。こうすると擬似 Finger /
  擬似 Combined は常に 12 角度を同数ずつ含み、検定するのは「同一角度集合のもとでの**割り当ての
  違い**」だけになる。

## A.4 統計量

2 条件の最大剛性角の円周差（楕円の硬い方向の回転量）:

$$
\Delta_{\max} = \text{circdiff}\bigl(\theta_{\max}^{\text{Finger}},\ \theta_{\max}^{\text{Combined}}\bigr)\in[0,180]
$$

$\theta_{\max}$ は A.5 の通り、各擬似条件で「角度平均 → `fit_cartesian` 楕円フィット →
原点から最遠点の角度」として再計算する。**1 回の並べ替えごとに楕円フィットを 2 回**行う点に注意
（軽くない計算。検定3全体で約 6 分）。

## A.5 アルゴリズム（擬似コード）

```
入力: 各試行の (stiffness, condition, angle)   # フィルタ後 190 試行
観測値の計算:
    θmax_F = ellipse_max_angle( mean_per_angle(Finger 試行) )
    θmax_C = ellipse_max_angle( mean_per_angle(Combined 試行) )
    Δ_obs  = circdiff(θmax_F, θmax_C)            # = 48.2°

帰無分布の構成:  for i in 1..N (=5000):
    perm = condition ラベルのコピー
    for each 角度 a in {0,30,...,330}:
        perm[a の試行] = shuffle(condition[a の試行])   # 層別シャッフル
    θF = ellipse_max_angle( mean_per_angle(perm=="Finger" の試行) )
    θC = ellipse_max_angle( mean_per_angle(perm=="Combined" の試行) )
    null[i] = circdiff(θF, θC)

p 値:
    p = ( #{ null[i] >= Δ_obs } + 1 ) / ( N + 1 )
```

- `ellipse_max_angle` = 角度平均 → `fit_cartesian` → 原点から最遠点の `atan2`（検定3本文 A 参照）。
- 乱数シードは `SEED=20250620` で固定（再現可能）。

## A.6 p 値の式と「+1」の理由

$$
p = \frac{\#\{\Delta^{(\text{perm})} \ge \Delta^{\text{obs}}\} + 1}{N + 1}
$$

- 分子・分母の **+1** は「観測した割り当てそのものも 1 つの並べ替え」として常に数える処理。
  これにより $p$ が厳密に 0 にならず（$N=5000$ でも下限 $1/5001\approx0.0002$）、モンテカルロ
  並べ替えで $p$ 値が不当に小さく出るのを防ぐ（Phipson & Smyth, 2010）。
- 片側検定（回転は向きを問わない大きさ $[0,180]$ なので、$\Delta$ が**大きい**ほど極端）。

## A.7 結果と帰無分布図（図B）

- 観測 $\Delta_{\max} = 48.2°$。
- 帰無分布: 中央値 16.6°、95 パーセンタイル 37.5°。観測 48° は分布のほぼ完全に外側。
- $\#\{\text{null} \ge 48.2°\} = 18$ 程度 / 5000 → **p = 0.0038**。

**図B**: `results/direction_ellipse_rotation_nulldist.png`
（`results/direction_ellipse_rotation_nulldist.npz` に帰無分布の生データを保存。再作図に使用可）

- 灰色ヒストグラム: 5000 回のラベルシャッフルで得た回転角の帰無分布。
- 黒の縦線: 観測値 48°。オレンジ破線: 95 パーセンタイル（有意ライン）37°。
- 緑の裾＋ズーム挿入図: 観測値以上の領域（p 値に相当する確率質量）。

並べ替え検定を採るときの**定番の図**であり、「観測値が帰無分布の裾にある」ことを視覚的に示す。
本文には楕円図（`direction_ellipse_rotation_repo.png`）に回転角と p を注記し、この図Bは
Supplementary に置く構成が一般的。

## A.8 並べ替え検定 vs ブートストラップ（役割の違い）

| | 並べ替え検定 | ブートストラップ |
|---|---|---|
| 操作 | 条件ラベルを**入れ替え**（$H_0$ を模す） | セル内反復を**復元抽出**（標本変動を模す） |
| 答える問い | 「向きの差は偶然か？」→ **p 値** | 「回転量はどれくらい不確か？」→ **信頼区間** |
| 本検定での扱い | **主たる推定**（p=0.0038） | 補助（95% CI [24°, 176°]、ただし上限が暴れる※） |

※ 原点オフセットのある楕円では、リサンプル時に楕円がほぼ円に近づくと $\theta_{\max}$ が ±180°
反転し得るため、角度差の対称 CI が不安定になる。p 値（並べ替え）を主とし、CI は分布が重裾で
ある旨を添えるのが誠実。

## A.9 参考文献

- Phipson, B., & Smyth, G. K. (2010). *Permutation P-values should never be zero.*
  Statistical Applications in Genetics and Molecular Biology, 9(1). — p 値の「+1」式の根拠。
- Ernst, M. D. (2004). *Permutation methods: A basis for exact inference.* Statistical Science, 19(4). — 並べ替え検定の解説と帰無分布図の例。
- Efron, B., & Tibshirani, R. J. (1993). *An Introduction to the Bootstrap.* Chapman & Hall. — 並べ替え／ブートストラップ分布をヒストグラムで示す原典的な図。
- Holmes, S., & Huber, W. (2019). *Modern Statistics for Modern Biology.* Cambridge UP（無料オンライン）. — 帰無分布ヒストグラム＋観測値線の見本が豊富。
- 円周データ一般: Pewsey, A., Neuhäuser, M., & Ruxton, G. D. (2013). *Circular Statistics in R.* Oxford UP.

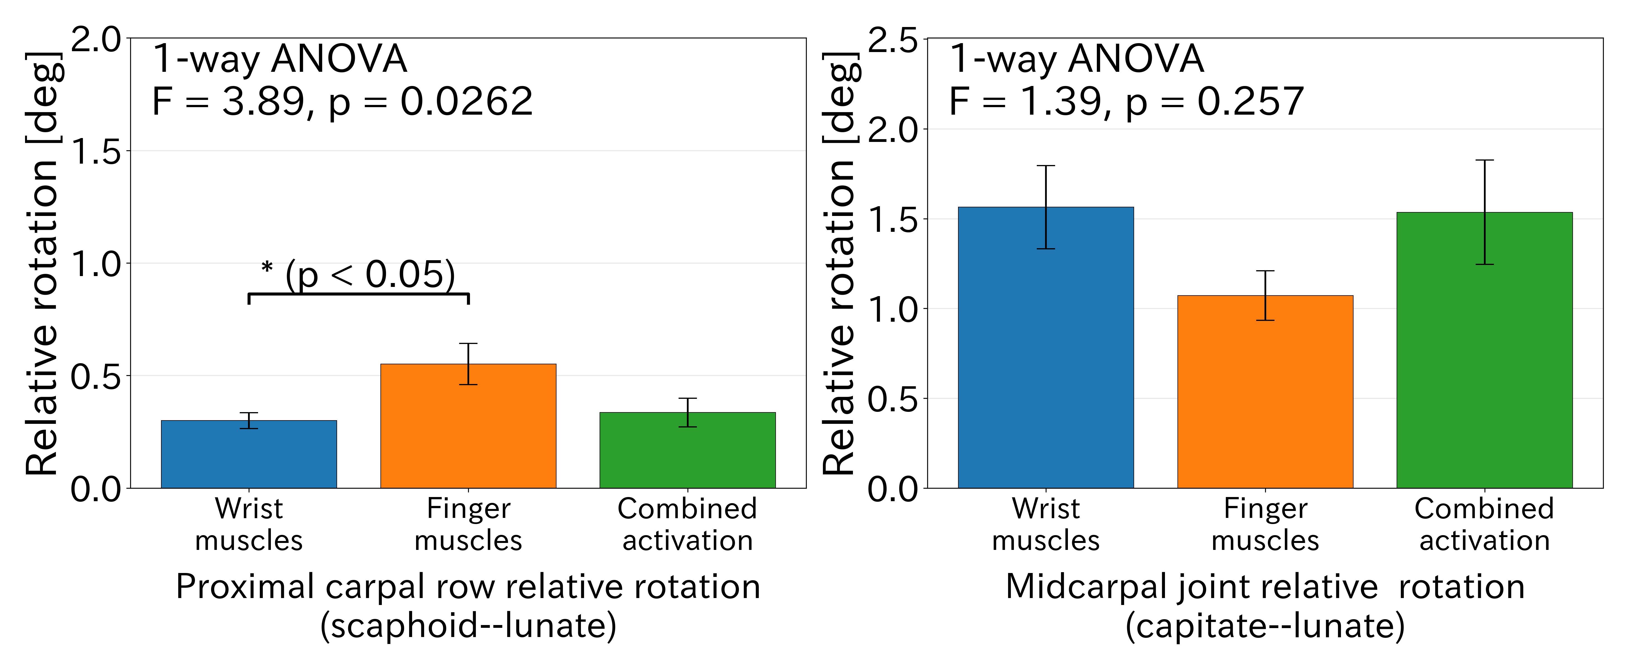
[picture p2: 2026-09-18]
analysis/figures_in_paper/carpal_relative_rotation.png

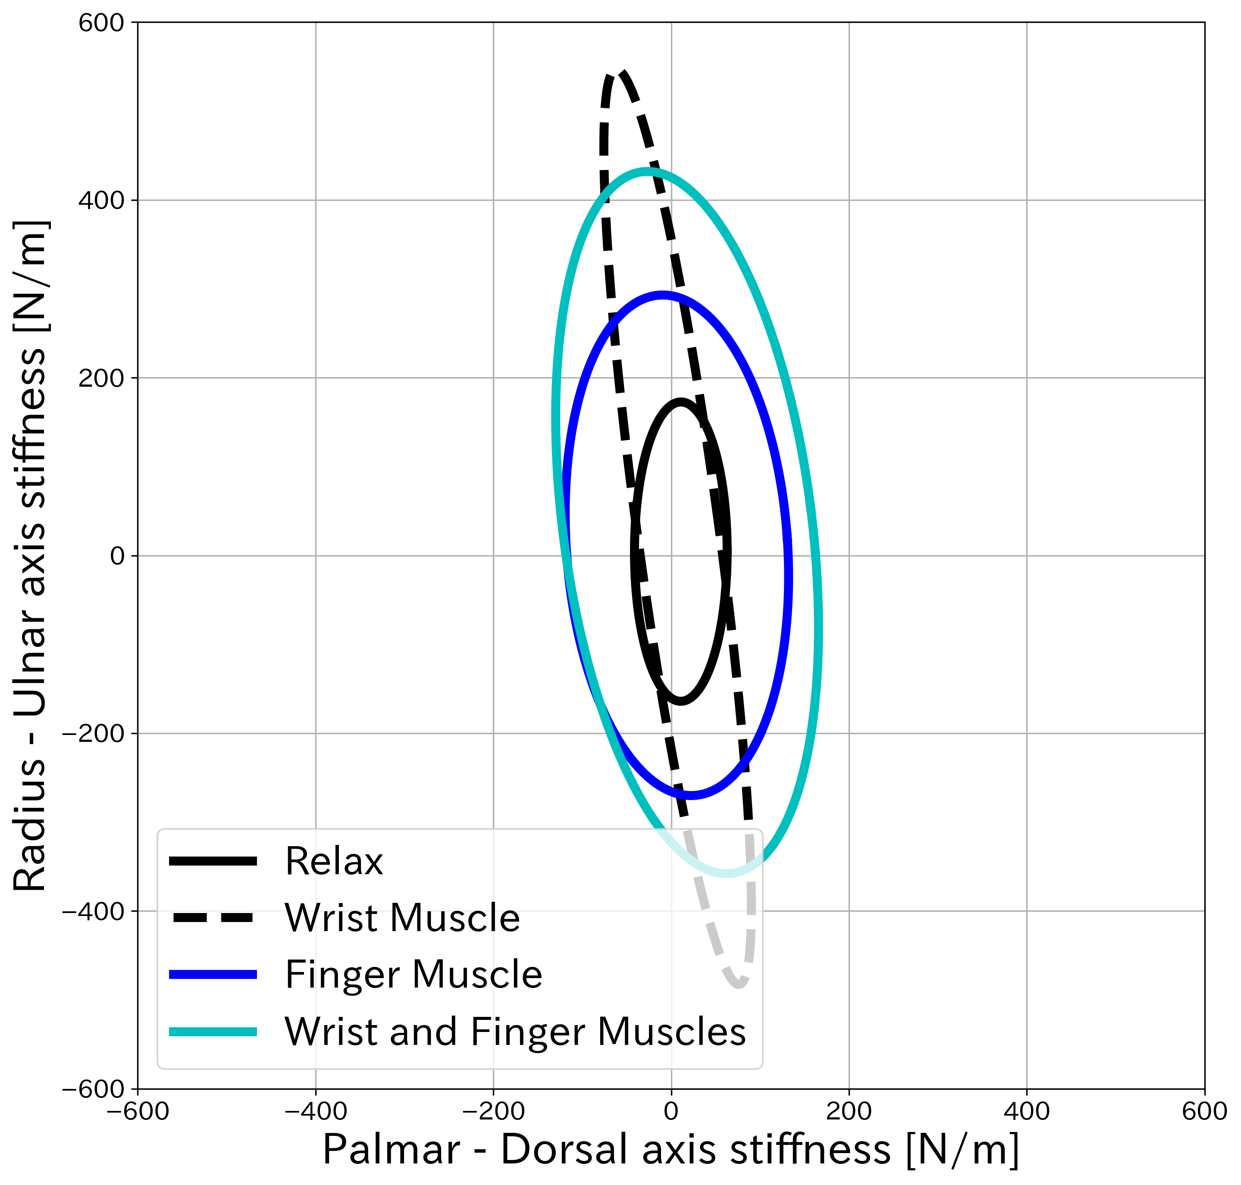
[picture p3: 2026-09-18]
analysis/figures_in_paper/fullres_ellipse/ellipse_cartesian_ellipse_carpal_0223.png

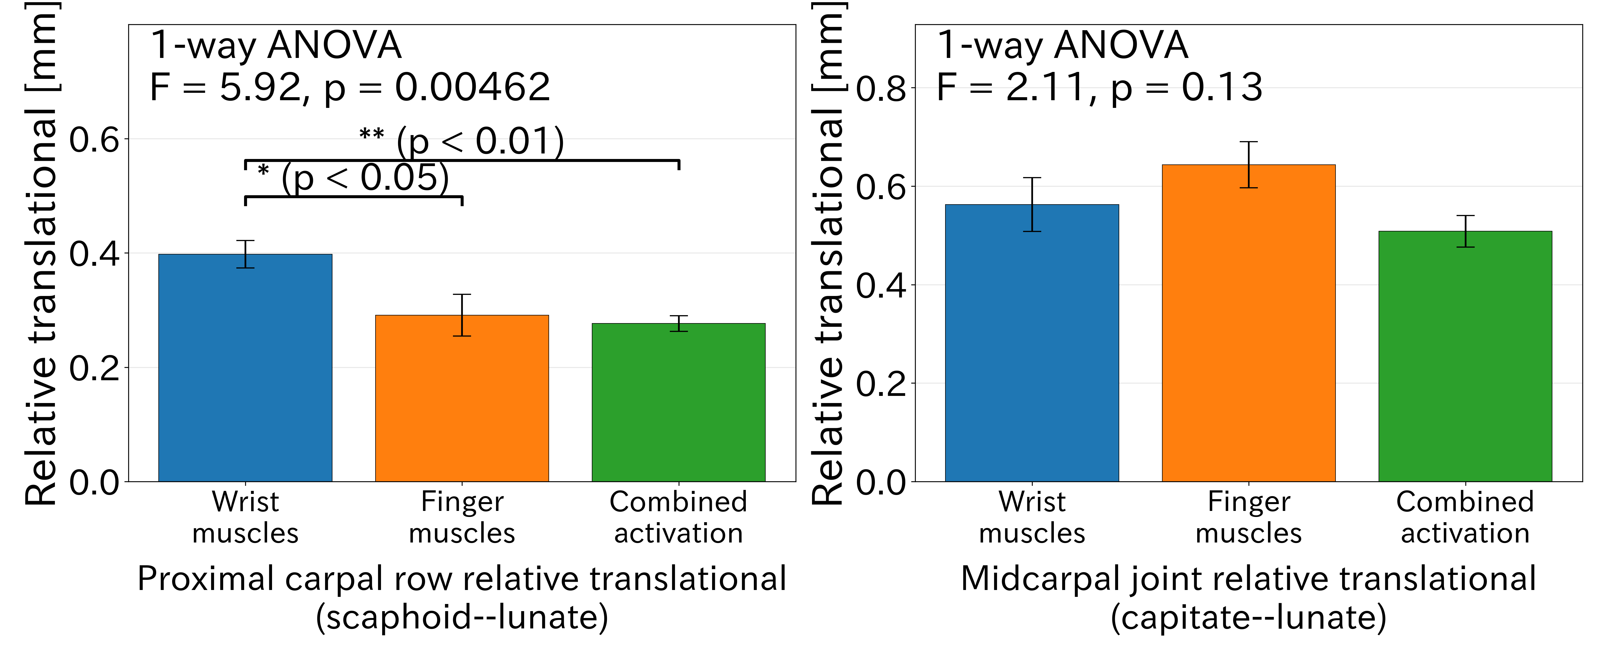
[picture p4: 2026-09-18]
analysis/figures_in_paper/carpal_relative_translational_motion.png

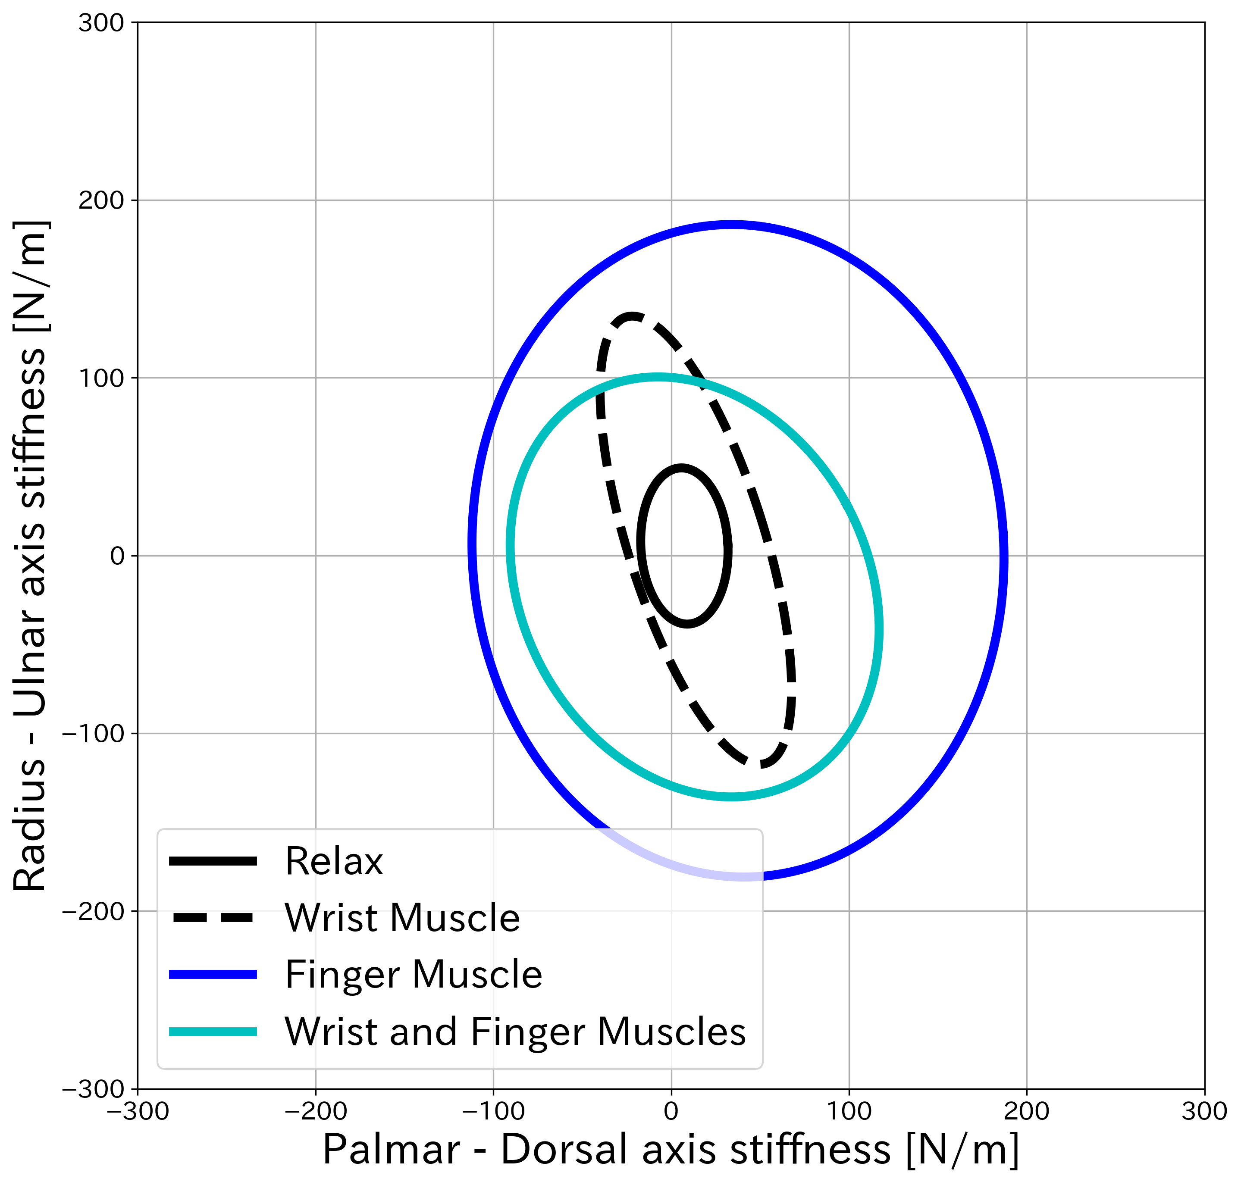
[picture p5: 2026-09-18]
analysis/figures_in_paper/fullres_ellipse/ellipse_cartesian_fixed_bone_0220.png

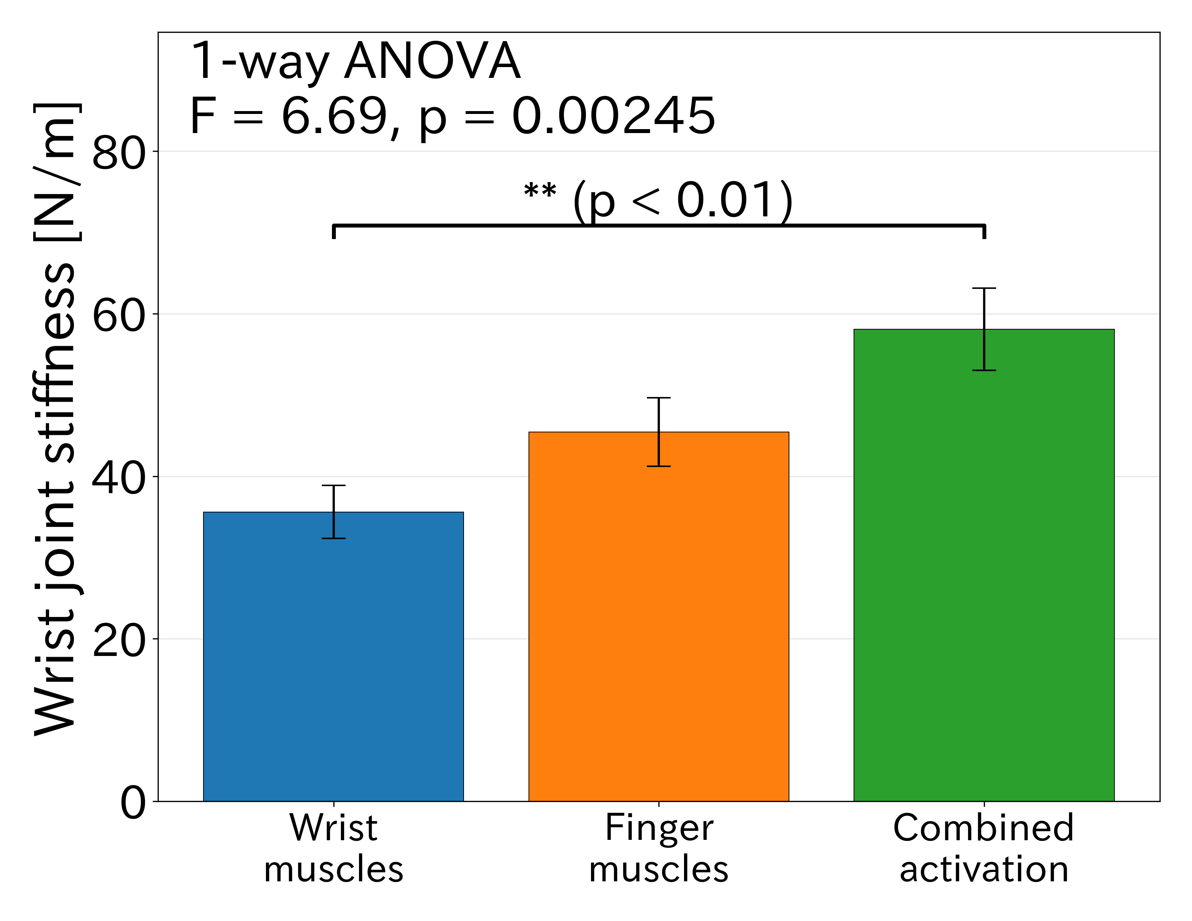
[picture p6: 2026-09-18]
analysis/figures_in_paper/wrist_stiffness.png

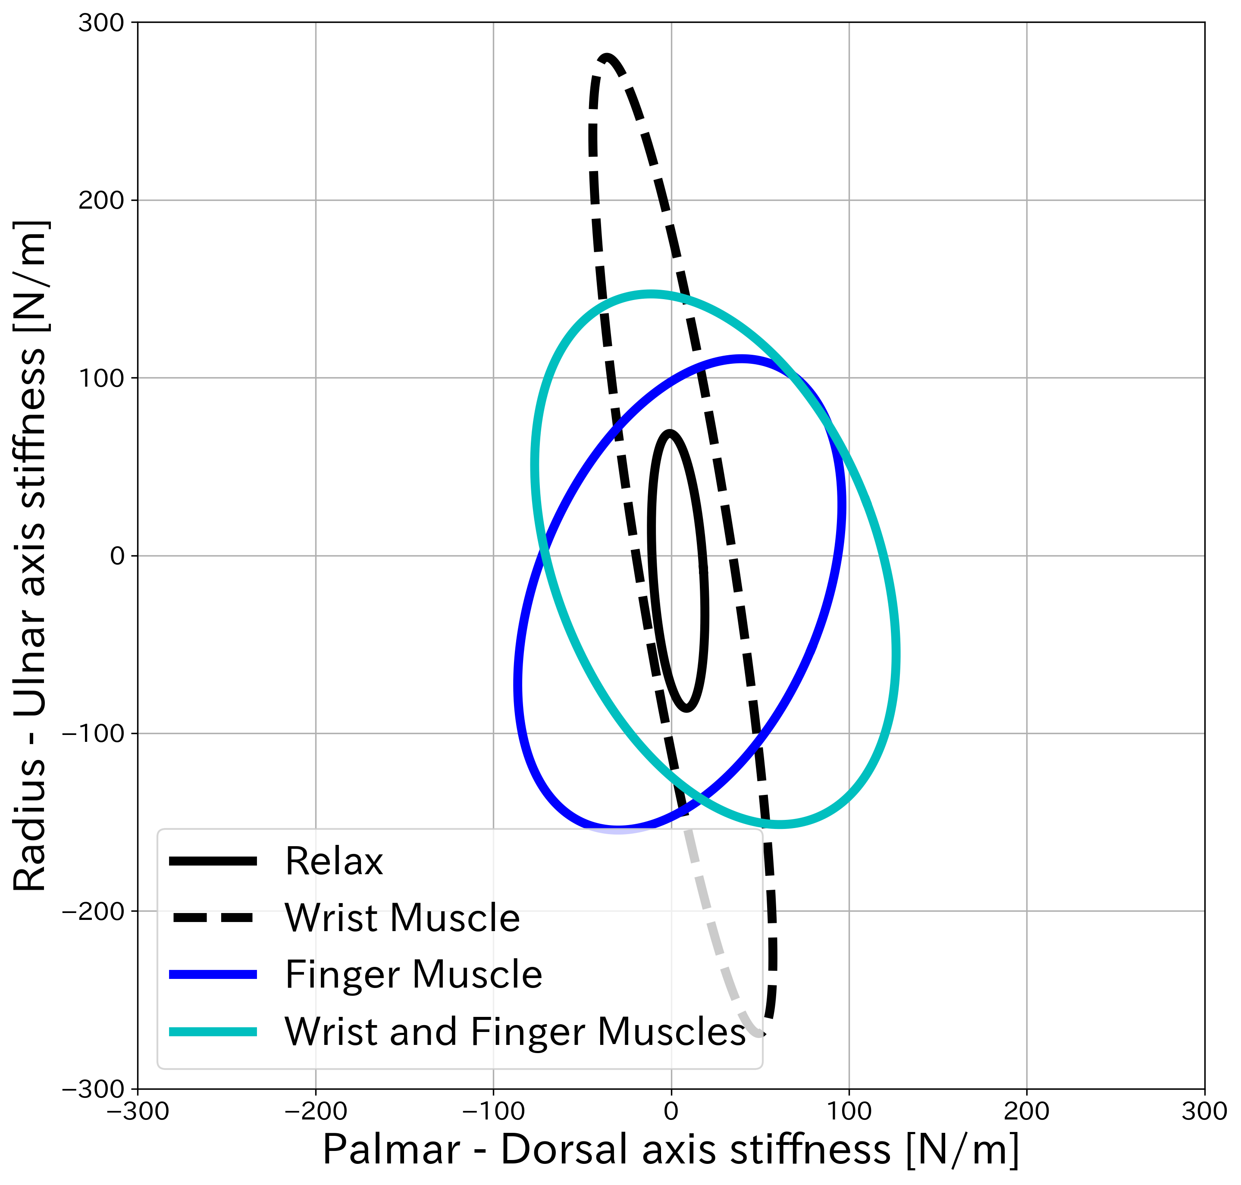
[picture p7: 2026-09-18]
analysis/figures_in_paper/fullres_ellipse/ellipse_cartesian_normal_0202.png

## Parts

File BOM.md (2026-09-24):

# Bill of Materials (BOM)

Print data for all 3D-printed parts is included in `stl/` of this repository. Only purchased components and the raw materials required for printing are listed below.

## Robotic forearm

| Component | Specification / Notes | Quantity |
| --- | --- | ---: |
| Servo motor (muscle actuator) | Dynamixel XL330-M288-T, Robotis; 12 mm radius pulley | 22 |
| Ligament | Chain-knitted polyethylene (PE) wire, φ0.23 mm | - |
| Tendon | Polyethylene (PE) wire, φ0.3 mm | - |
| Tendon sheath | PTFE tube, outer diameter 2 mm | - |
| Fingertip skin (outer layer) | Shore E30 silicone, 1 mm thickness (Young's modulus 22.1 kPa) | - |
| Fingertip subcutaneous tissue (inner layer) | Expanded silicone | - |

## 3D-printed parts and printing materials

See `stl/` (STL) and `cad/` (STEP, F3D) for the print data.

| Part group | Process / Material | Data |
| --- | --- | --- |
| Bones (carpals, metacarpals, phalanges, radius, ulna) and fingernails | Stereolithography (SLA) / White Resin, Formlabs | `stl/bone_*.stl` |
| Triangular fibrocartilage disc (TFCC) | Fused deposition modeling (FDM) / TPU | `stl/soft_tissue_tfcc.stl` |
| Fingertip molds | Stereolithography (SLA) / White Resin, Formlabs | `stl/mold_*.stl` |
| Base plate, motor tower and pulleys | Fused deposition modeling (FDM) / PolyLite ASA, Polymaker | `stl/tower_*.stl` |
| Assembly jigs (ligament length, carpal bones) | Fused deposition modeling (FDM) / PolyLite ASA, Polymaker | `stl/jig_*.stl` |
| Experimental jigs (humerus fixation, hand fixation, force gauge) | Fused deposition modeling (FDM) / PolyLite ASA, Polymaker | `stl/exp_*.stl` |

## Control system

| Component | Specification / Notes | Quantity |
| --- | --- | ---: |
| Microcontroller board | Teensy 4.1 (SDIO and I/O count required) | 1 |
| Dynamixel interface board | TTL2DXIF (BTE094B), Best Technology; TTL / RS-485 conversion. Connected to Teensy Serial2 (pins 7–8), direction control pin 2 | 1 |
| microSD card | 32 GB (used via the built-in SDIO of Teensy 4.1) | 1 |
| DC-DC converter (5 V supply) | AE-MYMGK00506ERSR-5V0 (5 V / 6 A DC-DC converter module kit based on MYMGK00506ERSR), Akizuki Denshi. Supplies the XL330-M288-T actuators. Sold as an assembly kit | 4 |

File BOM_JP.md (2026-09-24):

# 部品表（BOM）

3Dプリント部品は本リポジトリの `stl/` に印刷用データを収録しています。購入部品と、印刷に必要な材料のみを以下に示します。

## ロボット前腕本体

| 部品 | 仕様・備考 | 数量 |
| --- | --- | ---: |
| サーボモータ（筋アクチュエータ） | Dynamixel XL330-M288-T, Robotis；半径12 mmプーリ | 22 |
| 靭帯 | 鎖編みポリエチレン（PE）ワイヤ φ0.23 mm | - |
| 腱 | ポリエチレン（PE）ワイヤ φ0.3 mm | - |
| 腱鞘 | PTFEチューブ 外径2 mm | - |
| 指先 表層（皮膚相当） | Shore E30シリコーン、厚さ1 mm（ヤング率22.1 kPa） | - |
| 指先 内層（皮下組織相当） | 発泡シリコーン | - |

## 3Dプリント部品と造形材料

印刷用データは `stl/`（STL）および `cad/`（STEP、F3D）を参照してください。

| 部品群 | 造形法・材料 | データ |
| --- | --- | --- |
| 骨（手根骨・中手骨・指節骨・橈骨・尺骨）、爪 | 光造形（SLA）／White Resin, Formlabs | `stl/bone_*.stl` |
| 三角線維軟骨（TFCC） | 熱溶解積層（FDM）／TPU | `stl/soft_tissue_tfcc.stl` |
| 指先モールド | 光造形（SLA）／White Resin, Formlabs | `stl/mold_*.stl` |
| ベースプレート・モータタワー・プーリ | 熱溶解積層（FDM）／PolyLite ASA, Polymaker | `stl/tower_*.stl` |
| 組立治具（靭帯長・手根骨） | 熱溶解積層（FDM）／PolyLite ASA, Polymaker | `stl/jig_*.stl` |
| 実験治具（上腕固定・手部固定・フォースゲージ） | 熱溶解積層（FDM）／PolyLite ASA, Polymaker | `stl/exp_*.stl` |

## 制御系

| 部品 | 仕様・備考 | 数量 |
| --- | --- | ---: |
| マイコンボード | Teensy 4.1（SDIOとI/O数のため必須） | 1 |
| Dynamixel通信インタフェース基板 | TTL2DXIF（BTE094B）, ベストテクノロジー；TTL／RS-485変換。Teensy側はSerial2（ピン7–8）、方向制御ピン2 | 1 |
| microSDカード | 32 GB（Teensy 4.1内蔵SDIOを使用） | 1 |
| DC-DCコンバータ（5 V電源） | AE-MYMGK00506ERSR-5V0（MYMGK00506ERSR使用 5V出力 最大6A 大電流DCDCコンバーターモジュールキット）, 秋月電子通商。XL330-M288-Tの駆動電源。組立キット | 4 |

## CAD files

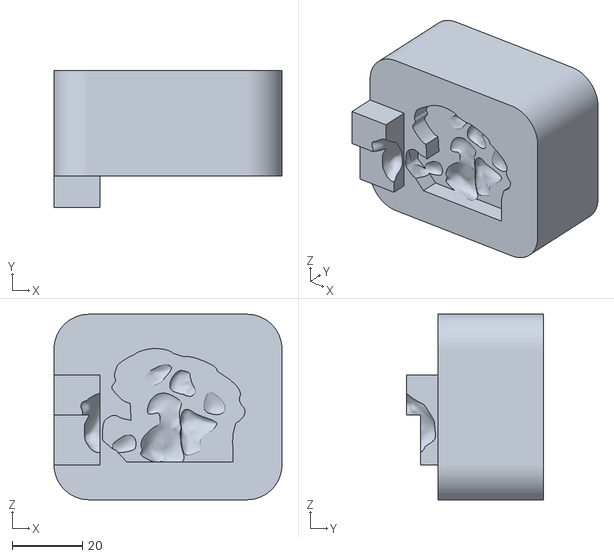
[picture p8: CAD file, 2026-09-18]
stl/jig_carpal_assemble_bottom.stl
65.0 x 39.0 x 52.9

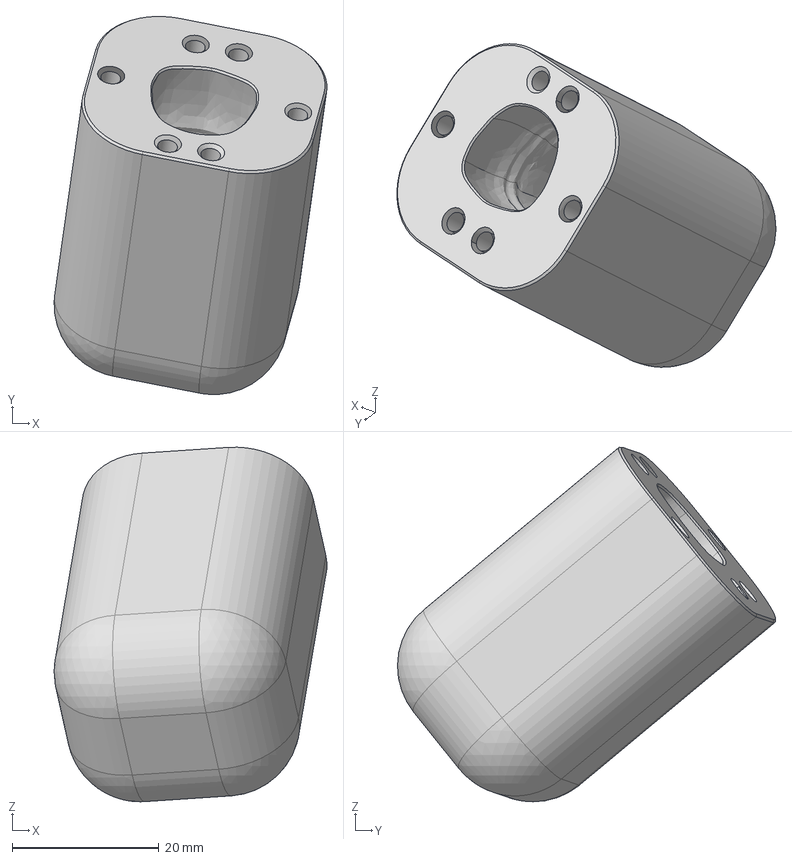
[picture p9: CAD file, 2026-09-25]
cad/mold_index_outer_fix.step
37.1 x 51.4 x 48.3 mm

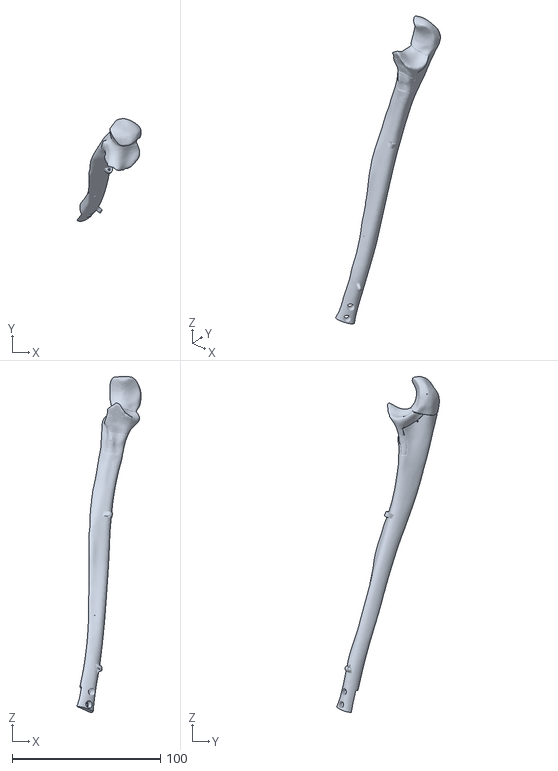
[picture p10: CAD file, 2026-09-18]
stl/bone_ulna_proximal.stl
43.4 x 69.2 x 226.4

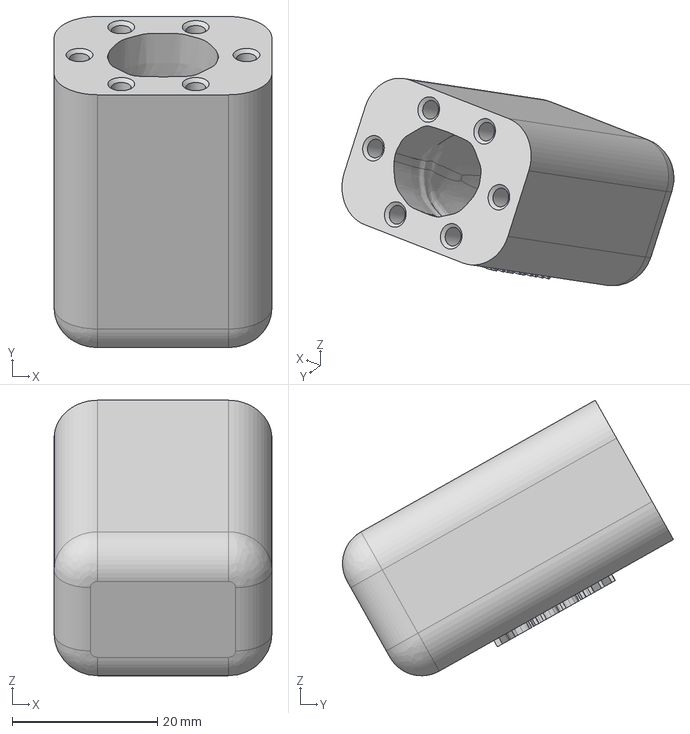
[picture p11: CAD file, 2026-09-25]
cad/mold_middle_outer_fix.step
30.0 x 45.6 x 37.9 mm

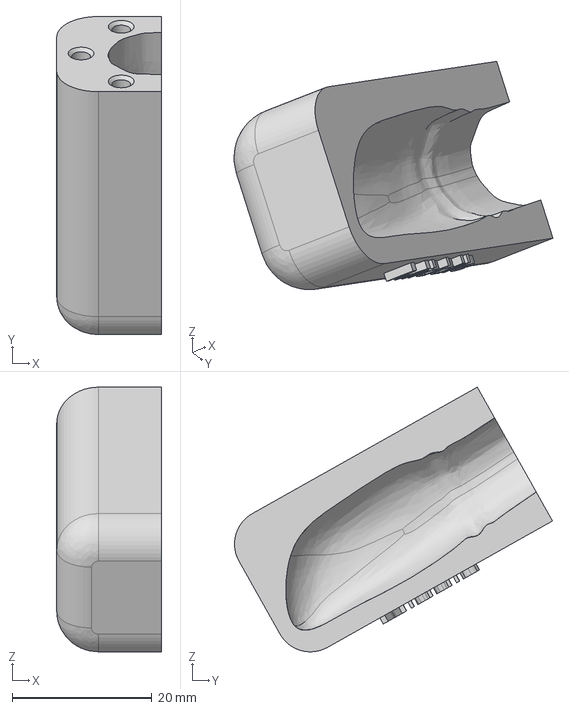
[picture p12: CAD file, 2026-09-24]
cad/mold_middle_outer_left.step
15.0 x 45.6 x 37.9 mm

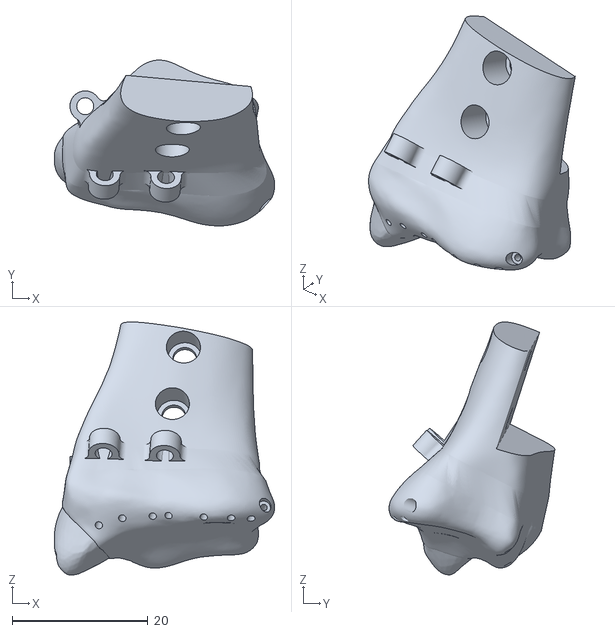
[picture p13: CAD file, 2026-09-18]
stl/bone_radius_distal.stl
32.5 x 24.4 x 37.2

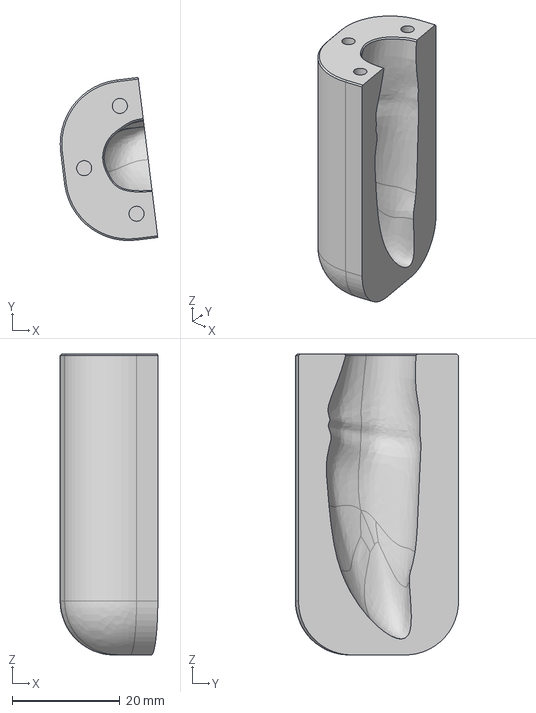
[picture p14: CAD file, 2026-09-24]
cad/mold_thumb_outer_left.step
18.2 x 30.4 x 56.0 mm

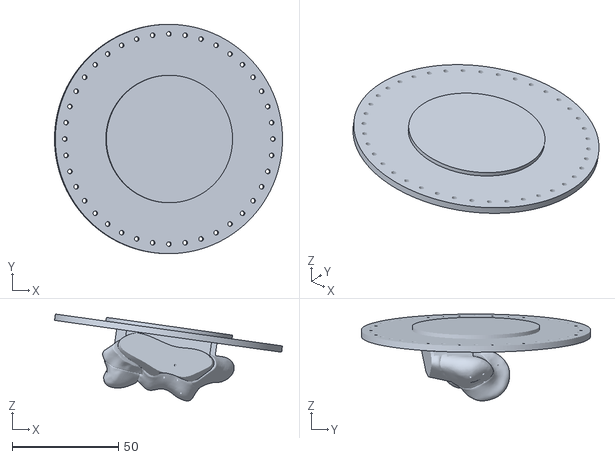
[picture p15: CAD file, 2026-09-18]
stl/bone_humerus_mount.stl
107.4 x 108.0 x 40.9

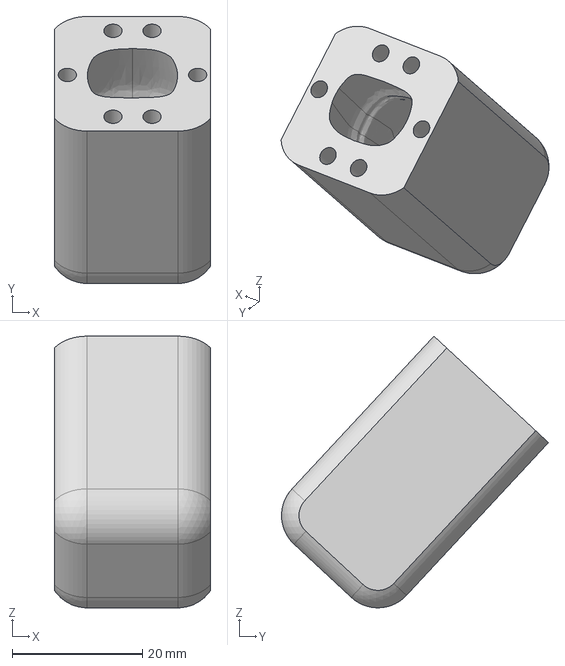
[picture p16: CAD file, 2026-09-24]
cad/mold_pinky_outer_fix.step
24.0 x 41.0 x 41.7 mm

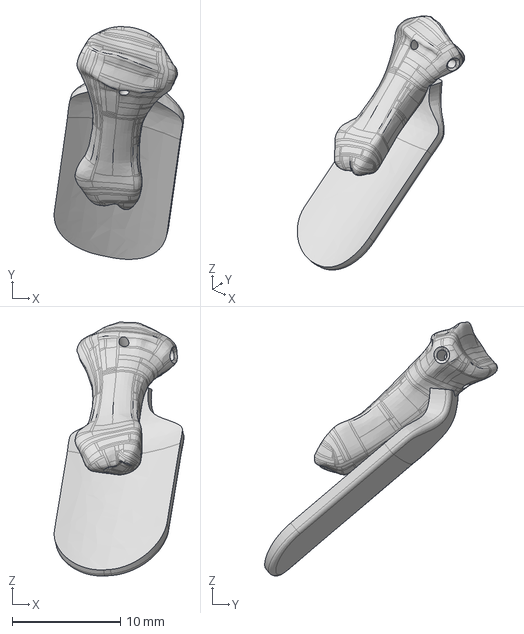
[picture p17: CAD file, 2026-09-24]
cad/bone_index_distal_phalanx_with_nail.step
12.0 x 21.5 x 23.5 mm

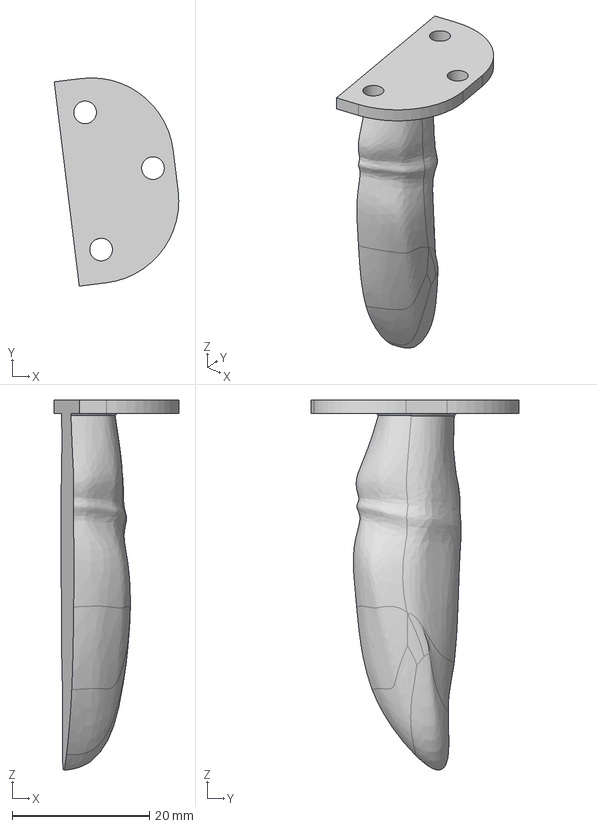
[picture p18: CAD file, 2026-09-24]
cad/mold_thumb_inner_right.step
18.2 x 30.4 x 53.9 mm

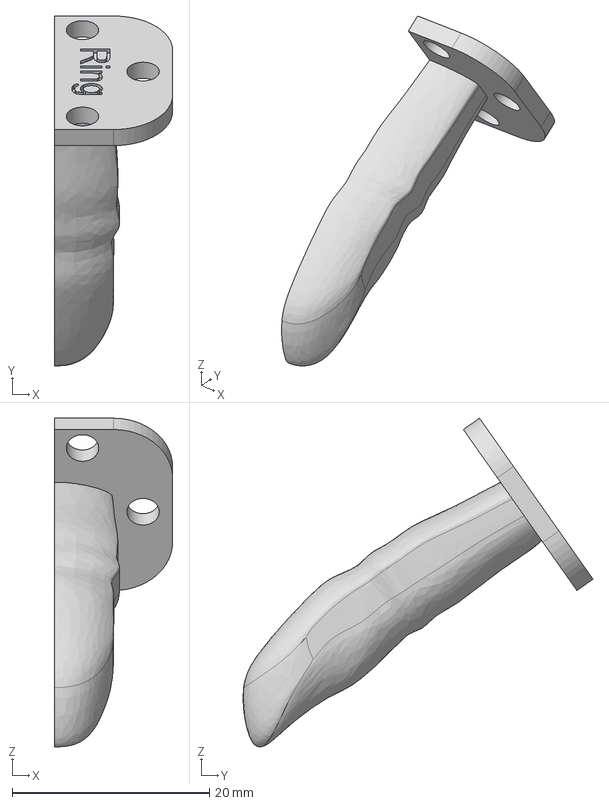
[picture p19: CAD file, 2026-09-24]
cad/mold_ring_inner_right.step
12.0 x 35.5 x 33.4 mm

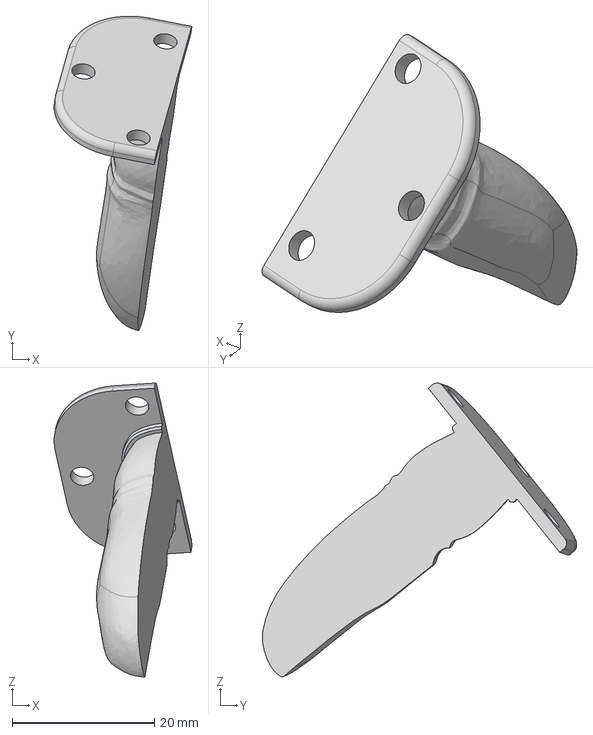
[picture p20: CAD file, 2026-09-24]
cad/mold_index_inner_left.step
19.4 x 44.2 x 41.3 mm

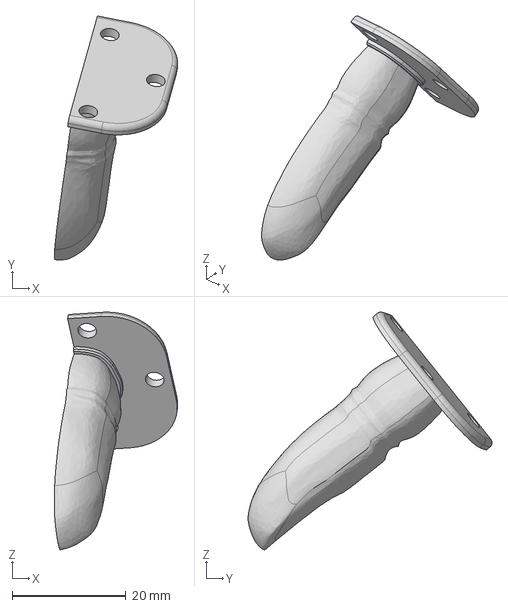
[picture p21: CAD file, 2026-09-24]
cad/mold_index_inner_right.step
21.7 x 42.9 x 41.8 mm

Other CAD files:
cad/mold_thumb_outer_fix.step
cad/mold_ring_outer_left.step
cad/mold_pinky_inner_left.step
cad/bone_pinky_distal_phalanx_with_nail.step
cad/bone_carpal_capitate.f3d
cad/bone_carpal_capitate.step
cad/bone_carpal_hamate.f3d
cad/bone_carpal_lunate.f3d
cad/bone_carpal_lunate.step
cad/bone_carpal_pisiform.f3d
cad/bone_carpal_pisiform.step
cad/bone_carpal_scaphoid.f3d
cad/bone_carpal_scaphoid.step
cad/bone_carpal_trapezium.f3d
cad/bone_carpal_trapezoid.f3d
cad/bone_carpal_trapezoid.step
cad/bone_carpal_triquetrum.f3d
cad/bone_carpal_triquetrum.step
cad/bone_ellipsoidal_carpal_attachment.f3d
cad/bone_ellipsoidal_carpal_attachment.step
cad/bone_ellipsoidal_carpal_distal.f3d
cad/bone_ellipsoidal_carpal_distal.step
cad/bone_ellipsoidal_carpal_proximal.f3d
cad/bone_ellipsoidal_carpal_proximal.step
cad/bone_index_distal_phalanx.f3d
cad/bone_index_distal_phalanx.step
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

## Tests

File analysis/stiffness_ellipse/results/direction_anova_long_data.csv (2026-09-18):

stiffness | condition | angle | rep | stiffness_norm
74.32066121343667 | Finger | 0 | 1 | 0.8238193285109501
0.4575503943244899 | Finger | 0 | 2 | 0.005071790972497076
57.435599663554896 | Finger | 0 | 3 | 0.6366541467058293
55.21007666468398 | Finger | 0 | 4 | 0.6119849789053678
132.71358334518717 | Finger | 0 | 5 | 1.471085070162799
36.958911828399295 | Finger | 0 | 6 | 0.4096770053959453
81.97825208003692 | Finger | 0 | 7 | 0.9087011266910997
108.99974721127984 | Finger | 0 | 8 | 1.2082252376304927
54.977704995763034 | Finger | 30 | 1 | 0.6094092177491847
71.80871692676178 | Finger | 30 | 2 | 0.7959752778564156
47.52872568315126 | Finger | 30 | 3 | 0.5268398079078963
79.05689248271246 | Finger | 30 | 4 | 0.8763188461447077
54.98790615316892 | Finger | 30 | 5 | 0.609522294119967
92.33454520107765 | Finger | 30 | 6 | 1.0234971242715931
92.25267578359842 | Finger | 30 | 7 | 1.0225896295395478
104.37893753680211 | Finger | 30 | 8 | 1.1570051292373114
50.85460202001377 | Finger | 60 | 1 | 0.5637060193464078
43.42324239946167 | Finger | 60 | 2 | 0.48133191781702334
106.38667675377656 | Finger | 60 | 3 | 1.1792602376627184
157.69910978035148 | Finger | 60 | 4 | 1.7480411584731153
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

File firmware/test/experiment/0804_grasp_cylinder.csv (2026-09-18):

timestamp | cur_1 | pos_1 | cur_2 | pos_2 | cur_3 | pos_3 | cur_4 | pos_4 | cur_5 | pos_5 | cur_6 | pos_6 | cur_7 | pos_7 | cur_8 | pos_8 | cur_9 | pos_9 | cur_10 | pos_10 | cur_11 | pos_11 | cur_12 | pos_12 | cur_13 | pos_13 | cur_14 | pos_14 | cur_15 | pos_15 | cur_16 | pos_16 | cur_17 | pos_17 | cur_18 | pos_18 | cur_19 | pos_19 | cur_20 | pos_20 | cur_21 | pos_21 | cur_22 | pos_22
4526726 | 12.00 | 2331.00 | 7.00 | 2333.00 | -3.00 | 173.00 | 37.00 | 2280.00 | 3.00 | 2976.00 | -1.00 | 2262.00 | -5.00 | 141.00 | 4.00 | 4563.00 | 17.00 | 1357.00 | 9.00 | 2331.00 | -8.00 | 2239.00 | 7.00 | 1643.00 | -14.00 | 1699.00 | -9.00 | 3336.00 | -10.00 | 4666.00 | 3.00 | 2274.00 | 16.00 | 3490.00 | 11.00 | 4272.00 | 1.00 | 1432.00 | 12.00 | 1529.00 | 9.00 | 1897.00 | -11.00 | 998.00
4526812 | 17.00 | 2336.00 | 15.00 | 2338.00 | -3.00 | 173.00 | 12.00 | 2317.00 | 4.00 | 2976.00 | -2.00 | 2262.00 | -3.00 | 141.00 | 8.00 | 4563.00 | 15.00 | 1374.00 | 11.00 | 2331.00 | 8.00 | 2239.00 | 11.00 | 1644.00 | -12.00 | 1683.00 | -8.00 | 3319.00 | -14.00 | 4657.00 | 5.00 | 2274.00 | 5.00 | 3516.00 | 11.00 | 4283.00 | 0.00 | 1432.00 | 15.00 | 1530.00 | 11.00 | 1898.00 | -5.00 | 995.00
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

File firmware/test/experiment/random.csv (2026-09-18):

timestamp | cur_1 | pos_1 | cur_2 | pos_2 | cur_3 | pos_3 | cur_4 | pos_4 | cur_5 | pos_5 | cur_6 | pos_6 | cur_7 | pos_7 | cur_8 | pos_8 | cur_9 | pos_9 | cur_10 | pos_10 | cur_11 | pos_11 | cur_12 | pos_12 | cur_13 | pos_13 | cur_14 | pos_14 | cur_15 | pos_15 | cur_16 | pos_16 | cur_17 | pos_17 | cur_18 | pos_18 | cur_19 | pos_19 | cur_20 | pos_20 | cur_21 | pos_21 | cur_22 | pos_22
102 | 0.00 | 2244 | 0.00 | 3039 | 0.00 | 1930 | 0.00 | 2418 | 0.00 | 3421 | 0.00 | 2422 | 24.00 | 216 | 42.00 | 932 | 0.00 | 1670 | 0.00 | 2485 | 0.00 | 2710 | 0.00 | 2108 | 0.00 | 1795 | 0.00 | 889 | 0.00 | 2160 | 0.00 | 1383 | 0.00 | 1898 | 0.00 | 1369 | 0.00 | 1920 | 13.00 | 93 | -1.00 | 1511 | -3.00 | 1469
151 | 0.00 | 2244 | 0.00 | 3039 | -1.00 | 1930 | 0.00 | 2418 | 0.00 | 3421 | 0.00 | 2420 | 25.00 | 256 | 63.00 | 940 | 0.00 | 1663 | 0.00 | 2483 | 0.00 | 2707 | 0.00 | 2108 | 0.00 | 1795 | 0.00 | 889 | 0.00 | 2159 | 0.00 | 1383 | 0.00 | 1894 | 0.00 | 1369 | 2.00 | 1920 | 15.00 | 103 | -5.00 | 1505 | -8.00 | 1453
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

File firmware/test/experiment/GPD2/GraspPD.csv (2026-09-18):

timestamp | cur_1 | pos_1 | cur_2 | pos_2 | cur_3 | pos_3 | cur_4 | pos_4 | cur_5 | pos_5 | cur_6 | pos_6 | cur_7 | pos_7 | cur_8 | pos_8 | cur_9 | pos_9 | cur_10 | pos_10 | cur_11 | pos_11 | cur_12 | pos_12 | cur_13 | pos_13 | cur_14 | pos_14 | cur_15 | pos_15 | cur_16 | pos_16 | cur_17 | pos_17 | cur_18 | pos_18 | cur_19 | pos_19 | cur_20 | pos_20 | cur_21 | pos_21 | cur_22 | pos_22
35 | 0.00 | 2670 | 0.00 | -621 | 0.00 | 3081 | 0.00 | 2727 | 0.00 | -589 | 0.00 | 3757 | 0.00 | 189 | 0.00 | 836 | -7.00 | 1557 | 0.00 | 1082 | 0.00 | 659 | 0.00 | 498 | 0.00 | 1565 | 0.00 | 3780 | 0.00 | 2026 | 0.00 | 1032 | 0.00 | 3172 | 0.00 | 1475 | 0.00 | 1037 | 0.00 | 1703 | 0.00 | 1509 | 0.00 | 1202
119 | 16.00 | 2671 | 0.00 | -621 | 0.00 | 3081 | 0.00 | 2727 | 17.00 | -588 | 16.00 | 3759 | 0.00 | 189 | 0.00 | 836 | 0.00 | 1557 | 50.00 | 1089 | 51.00 | 668 | 1.00 | 498 | -3.00 | 1565 | 1.00 | 3780 | -7.00 | 2025 | 195.00 | 1076 | 193.00 | 3214 | 4.00 | 1475 | 11.00 | 1037 | -1.00 | 1703 | 50.00 | 1528 | 0.00 | 1202
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

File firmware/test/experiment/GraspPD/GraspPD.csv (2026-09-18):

timestamp | cur_1 | pos_1 | cur_2 | pos_2 | cur_3 | pos_3 | cur_4 | pos_4 | cur_5 | pos_5 | cur_6 | pos_6 | cur_7 | pos_7 | cur_8 | pos_8 | cur_9 | pos_9 | cur_10 | pos_10 | cur_11 | pos_11 | cur_12 | pos_12 | cur_13 | pos_13 | cur_14 | pos_14 | cur_15 | pos_15 | cur_16 | pos_16 | cur_17 | pos_17 | cur_18 | pos_18 | cur_19 | pos_19 | cur_20 | pos_20 | cur_21 | pos_21 | cur_22 | pos_22
8233851 | 0.00 | 3414.00 | 0.00 | -407.00 | 0.00 | 415.00 | 0.00 | 2972.00 | 0.00 | -578.00 | 0.00 | -341.00 | 0.00 | 418.00 | 0.00 | 763.00 | 0.00 | 2100.00 | 0.00 | 786.00 | 0.00 | 1769.00 | 0.00 | 856.00 | 0.00 | 486.00 | 0.00 | 1782.00 | 0.00 | 1026.00 | 0.00 | 2599.00 | 0.00 | -275.00 | 0.00 | 814.00 | 0.00 | 1748.00 | 0.00 | 1648.00 | 0.00 | 1914.00 | 0.00 | 926.00
8233954 | 0.00 | 3414.00 | 0.00 | -407.00 | -7.00 | 415.00 | 0.00 | 2972.00 | 0.00 | -578.00 | 3.00 | -341.00 | -8.00 | 418.00 | -2.00 | 763.00 | 0.00 | 2100.00 | 3.00 | 787.00 | 1.00 | 1769.00 | 4.00 | 856.00 | -8.00 | 486.00 | 5.00 | 1782.00 | 47.00 | 1046.00 | 1.00 | 2599.00 | 1.00 | -275.00 | 5.00 | 814.00 | 8.00 | 1748.00 | 0.00 | 1648.00 | 37.00 | 1941.00 | 1.00 | 926.00
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

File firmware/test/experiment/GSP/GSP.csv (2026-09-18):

timestamp | cur_1 | pos_1 | cur_2 | pos_2 | cur_3 | pos_3 | cur_4 | pos_4 | cur_5 | pos_5 | cur_6 | pos_6 | cur_7 | pos_7 | cur_8 | pos_8 | cur_9 | pos_9 | cur_10 | pos_10 | cur_11 | pos_11 | cur_12 | pos_12 | cur_13 | pos_13 | cur_14 | pos_14 | cur_15 | pos_15 | cur_16 | pos_16 | cur_17 | pos_17 | cur_18 | pos_18 | cur_19 | pos_19 | cur_20 | pos_20 | cur_21 | pos_21 | cur_22 | pos_22
36 | 30.00 | 3642 | 0.00 | 935 | 4.00 | 3019 | 0.00 | 4250 | 0.00 | 4358 | 100.00 | 4974 | 1.00 | 185 | 9.00 | 757 | -8.00 | 1731 | 30.00 | 2533 | 9.00 | 1736 | 16.00 | 1528 | 15.00 | 796 | 1.00 | 592 | 12.00 | 1942 | 28.00 | 1019 | 0.00 | 3228 | 47.00 | 1852 | 0.00 | 2007 | 51.00 | 6040 | 45.00 | 1721 | -11.00 | -523
119 | 15.00 | 3642 | 0.00 | 935 | 9.00 | 3019 | 0.00 | 4250 | 17.00 | 4359 | 18.00 | 4968 | 3.00 | 185 | 0.00 | 757 | -1.00 | 1731 | -34.00 | 2515 | -10.00 | 1736 | -6.00 | 1527 | 6.00 | 796 | -8.00 | 591 | -7.00 | 1941 | 2.00 | 1017 | 6.00 | 3228 | 2.00 | 1847 | 1.00 | 2006 | 4.00 | 6034 | 9.00 | 1712 | 14.00 | -521
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

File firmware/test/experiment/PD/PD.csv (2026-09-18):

timestamp | cur_1 | pos_1 | cur_2 | pos_2 | cur_3 | pos_3 | cur_4 | pos_4 | cur_5 | pos_5 | cur_6 | pos_6 | cur_7 | pos_7 | cur_8 | pos_8 | cur_9 | pos_9 | cur_10 | pos_10 | cur_11 | pos_11 | cur_12 | pos_12 | cur_13 | pos_13 | cur_14 | pos_14 | cur_15 | pos_15 | cur_16 | pos_16 | cur_17 | pos_17 | cur_18 | pos_18 | cur_19 | pos_19 | cur_20 | pos_20 | cur_21 | pos_21 | cur_22 | pos_22
2427215 | -10.00 | 2340.00 | -12.00 | 2683.00 | -2.00 | 173.00 | -8.00 | 2112.00 | -7.00 | 2984.00 | 16.00 | 2471.00 | 2.00 | 141.00 | -6.00 | 530.00 | -8.00 | 1531.00 | 37.00 | 2735.00 | 12.00 | 2238.00 | 27.00 | 1972.00 | 12.00 | 2135.00 | 15.00 | 3655.00 | -12.00 | 4864.00 | -7.00 | 2520.00 | -8.00 | 3532.00 | 49.00 | 4971.00 | -10.00 | 1122.00 | -5.00 | 1595.00 | -2.00 | 1979.00 | -9.00 | 691.00
2427373 | -4.00 | 2340.00 | -11.00 | 2683.00 | -2.00 | 173.00 | -12.00 | 2112.00 | -9.00 | 2984.00 | -3.00 | 2470.00 | -4.00 | 141.00 | -6.00 | 530.00 | -4.00 | 1531.00 | 26.00 | 2730.00 | 16.00 | 2238.00 | 26.00 | 1972.00 | 10.00 | 2135.00 | 7.00 | 3655.00 | 8.00 | 4884.00 | -4.00 | 2520.00 | -12.00 | 3532.00 | 18.00 | 4962.00 | 2.00 | 1122.00 | 4.00 | 1623.00 | 26.00 | 1993.00 | -3.00 | 691.00
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

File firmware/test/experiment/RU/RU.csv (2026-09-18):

timestamp | cur_1 | pos_1 | cur_2 | pos_2 | cur_3 | pos_3 | cur_4 | pos_4 | cur_5 | pos_5 | cur_6 | pos_6 | cur_7 | pos_7 | cur_8 | pos_8 | cur_9 | pos_9 | cur_10 | pos_10 | cur_11 | pos_11 | cur_12 | pos_12 | cur_13 | pos_13 | cur_14 | pos_14 | cur_15 | pos_15 | cur_16 | pos_16 | cur_17 | pos_17 | cur_18 | pos_18 | cur_19 | pos_19 | cur_20 | pos_20 | cur_21 | pos_21 | cur_22 | pos_22
3435887 | -7.00 | 2341.00 | -5.00 | 2678.00 | -4.00 | 173.00 | -3.00 | 2115.00 | -4.00 | 2968.00 | 27.00 | 2545.00 | 1.00 | 141.00 | 56.00 | 533.00 | 0.00 | 1529.00 | 16.00 | 2791.00 | -3.00 | 2261.00 | 17.00 | 2036.00 | 31.00 | 2116.00 | 3.00 | 3649.00 | 3.00 | 4817.00 | 18.00 | 2487.00 | -9.00 | 3519.00 | 10.00 | 5013.00 | -9.00 | 1122.00 | 1.00 | 1597.00 | 25.00 | 2019.00 | 2.00 | 691.00
3435973 | -9.00 | 2341.00 | -12.00 | 2677.00 | -2.00 | 173.00 | -12.00 | 2115.00 | -7.00 | 2963.00 | 3.00 | 2577.00 | 2.00 | 140.00 | 39.00 | 558.00 | -1.00 | 1529.00 | 16.00 | 2802.00 | -2.00 | 2261.00 | 13.00 | 2041.00 | 31.00 | 2118.00 | 8.00 | 3649.00 | 8.00 | 4817.00 | 14.00 | 2487.00 | -9.00 | 3502.00 | 5.00 | 5019.00 | -15.00 | 1117.00 | 0.00 | 1597.00 | 30.00 | 2025.00 | 4.00 | 691.00
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

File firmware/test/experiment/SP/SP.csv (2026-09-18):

timestamp | cur_1 | pos_1 | cur_2 | pos_2 | cur_3 | pos_3 | cur_4 | pos_4 | cur_5 | pos_5 | cur_6 | pos_6 | cur_7 | pos_7 | cur_8 | pos_8 | cur_9 | pos_9 | cur_10 | pos_10 | cur_11 | pos_11 | cur_12 | pos_12 | cur_13 | pos_13 | cur_14 | pos_14 | cur_15 | pos_15 | cur_16 | pos_16 | cur_17 | pos_17 | cur_18 | pos_18 | cur_19 | pos_19 | cur_20 | pos_20 | cur_21 | pos_21 | cur_22 | pos_22
4719337 | 0.00 | 2043.00 | 0.00 | 2932.00 | 0.00 | 415.00 | 0.00 | 2222.00 | 0.00 | 3029.00 | 0.00 | 2633.00 | 0.00 | 417.00 | 0.00 | 4343.00 | 0.00 | 878.00 | 0.00 | 2553.00 | 0.00 | 2388.00 | 0.00 | 2542.00 | 0.00 | 1386.00 | 0.00 | 2534.00 | 0.00 | 2033.00 | 0.00 | 2752.00 | 0.00 | 3232.00 | 0.00 | 1796.00 | 0.00 | 1795.00 | 0.00 | 1644.00 | 0.00 | 2155.00 | 0.00 | 795.00
4719438 | 35.00 | 2047.00 | 57.00 | 2939.00 | -7.00 | 415.00 | 0.00 | 2222.00 | 4.00 | 3029.00 | -29.00 | 2628.00 | -7.00 | 417.00 | 36.00 | 4351.00 | 2.00 | 878.00 | -5.00 | 2553.00 | 2.00 | 2388.00 | -2.00 | 2542.00 | -2.00 | 1386.00 | 2.00 | 2534.00 | -6.00 | 2033.00 | 2.00 | 2752.00 | 5.00 | 3232.00 | -1.00 | 1795.00 | 1.00 | 1795.00 | 2.00 | 1644.00 | -32.00 | 2145.00 | 7.00 | 795.00
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

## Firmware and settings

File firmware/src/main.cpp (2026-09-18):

#include <Dynamixel2Arduino.h>
#include <TeensyThreads.h>
#include "DXLSetup.h"
#include "muscle.h"
#include "SDControl.h"
#include "control.h"
#include "motion.h"
#include "tests.h"
#include "logging.h"
#include "teaching.h"

// RCサーボモード用のコード
#include <Servo.h>

const int SERVO_PIN = 9;  // Teensyのサーボ対応ピンを使用
Servo actuator;        // PWMServoオブジェクト

// 0-100%の位置をサーボパルスに変換
void setPosition(float percentage) {
  // 位置を0-100%で指定
  percentage = constrain(percentage, 0.0f, 100.0f);
  
  // 12bit解像度（0-4095）にマッピング
  int pwmValue = map(percentage * 10, 0, 1000, 0, 4095);
  DEBUG_SERIAL.println(pwmValue);
  analogWrite(SERVO_PIN, pwmValue);
}

void Start(uint8_t row_cnt, MotionType motion){
  // 現在の電流値とモーターのポジションを取得
  currentAndPositionCheck();
  DISPLAY_SERIAL.println("start");

  // モーションデータを１行ずつ読み込んで再生する
  for (uint8_t i = 0; i < row_cnt; i++)
  {
    uint8_t moving_time = MOVING_TIME;
    uint32_t start_time = millis();
    currentAndPositionCheck();
    // トルク制御するモーターのインデックス
    int8_t torque_control_flags[SERVO_NUM] = {};
    int32_t e_angles[SERVO_NUM] = {};
    computeEAngles(e_angles, playback_positions[i]);

    if (motion == MotionType::Grasp) {
      coopGraspMotion(e_angles, torque_control_flags, moving_time);
    }else if(motion == MotionType::Relax){
      relaxMotion(e_angles, playback_positions[i]);
    }
      sweepRunGoalPosition(playback_positions[i], e_angles, torque_control_flags, moving_time, start_time);
    // DEBUG_SERIAL.println("Finish");
  }
  DEBUG_SERIAL.println("Finish");
  DISPLAY_SERIAL.println("Finish");
}

static void cmdTeach(){
  listFiles();
  if (initFileName()){
    DEBUG_SERIAL.println("無限巻取り機構を使いますか？ y/n");
    waitForSerialInput();
    String input = DEBUG_SERIAL.readStringUntil('\n');
    input.trim();
    if (input.equalsIgnoreCase("Y")){
      teachingMode(true);
      DEBUG_SERIAL.println("無限巻取り機構を使います");
    }
    else{
      teachingMode(false);
      DEBUG_SERIAL.println("無限巻取り機構を使いません");
    }
  }
}

static void cmdStart(){
  DEBUG_SERIAL.println("How many times?");
  waitForSerialInput();
  String input = DEBUG_SERIAL.readStringUntil('\n');
  input.trim();
  if (chooseFile() && input.toInt()){
    DEBUG_SERIAL.println("Which motion type? relax: 1, grasp: 2\nmotion type: ");
    waitForSerialInput();
    String motion_type = DEBUG_SERIAL.readStringUntil('\n');
    motion_type.trim();
    uint8_t row_cnt = readAllData();
    printCsvHeader(DEBUG_SERIAL);
    for (uint8_t i = 0; i < input.toInt(); i++)
    {
      if (motion_type == "2"){
        Start(row_cnt, MotionType::Grasp);
      }else{
        Start(row_cnt, MotionType::Relax);
      }
    }
  }else{
    DEBUG_SERIAL.println("Failure.. Please check your input");
  }
}

static void cmdDelete(){
  deleteFile();
}

static void cmdLs(){
  listFiles();
}

static void cmdRelax(){
  for (uint8_t i = 0; i < SERVO_NUM; i++)
  {
    dxl.torqueOff(i);
  }
}

static void cmdFix(){
  fix();
}

static void cmdManual(){
  DEBUG_SERIAL.println("Manual move. Please input 22 servo positions, like 3200, 4300, 3444");
  waitForSerialInput();
  String input = DEBUG_SERIAL.readStringUntil('\n');
  input.trim();
  char buf[256];
  input.toCharArray(buf, sizeof(buf));
  char* token = strtok(buf, ",");
  int count = 0;
  int32_t target[SERVO_NUM] = {};
  while (token != NULL && count < SERVO_NUM) {
    target[count] = atoi(token);
    DEBUG_SERIAL.println(target[count]);
    count++;
    token = strtok(NULL, ",");
  }
}

static void cmdStatic(){
  DEBUG_SERIAL.println("関節剛性計測モード\nモードを選択してください\n1: 低剛性\n2: 高剛性\n3: 高剛性かつ把持\n4: 指筋のみ");
  waitForSerialInput();
  String input = DEBUG_SERIAL.readStringUntil('\n');
  input.trim();
  contractionTest(atoi(input.c_str()));
}

static void cmdRandom(){
  DEBUG_SERIAL.println("ランダム筋駆動モーションテスト\nモードを選択してください\n1: FE\n2: RU\n3: DTM");
  waitForSerialInput();
  String input = DEBUG_SERIAL.readStringUntil('\n');
  input.trim();
  randomTest(atoi(input.c_str()));
}

static void cmdUnit(){
  DEBUG_SERIAL.println("筋肉単体テスト");
  unitDriveTest();
}

static void cmdFingerDrive(){
  DEBUG_SERIAL.println("指の番号を入力してください");
  waitForSerialInput();
  uint8_t finger = DEBUG_SERIAL.parseInt();
  fingerDriveTest(finger);
}

static void cmdDirection(){
  DEBUG_SERIAL.println("方向性確認: サーボ ID (0-21) を入力してください");
  waitForSerialInput();
  uint8_t id = DEBUG_SERIAL.parseInt();
  directionTest(id);
}

static void cmdDirectionAll(){
  DEBUG_SERIAL.println("全サーボ方向性確認を開始します。実機が±20mAで動きます。y/n");
  waitForSerialInput();
  String input = DEBUG_SERIAL.readStringUntil('\n');
  input.trim();
  if (input.equalsIgnoreCase("Y")) directionTestAll();
  else DEBUG_SERIAL.println("cancelled");
}

static void cmdServo(){
  DEBUG_SERIAL.println("サーボテスト　角度: ");
  waitForSerialInput();
  float pos = DEBUG_SERIAL.parseFloat();
  if (pos >= 0 && pos <= 100) {
    setPosition(pos);
    DEBUG_SERIAL.print("Position set to: ");
    DEBUG_SERIAL.print(pos);
    DEBUG_SERIAL.println("%");
  }
}

static void cmdShow(){
  float pos[SERVO_NUM] = {};
  String positions = "";
  currentAndPositionCheck();
  for (uint8_t i = 0; i < SERVO_NUM; i++)
  {
    pos[i] = dxl.getPresentPosition(i, UNIT_RAW);
  }
  for (uint8_t i = 0; i < SERVO_NUM; i++)
  {
    positions += String(int(pos[i])) + ",";
  }
  DEBUG_SERIAL.println(positions);
}

// Host-scripted single-line goal command. Two-line protocol:
//   >> Goal\n
//   >> 1234,5678,...,2048\n      (22 ints, comma-separated; optional ':' prefix)
//   << OK\n                       (success: motors driven)
//   << ERR:<reason>\n             (parse error or wrong count)
// See unit_test/docs/proposed_goal_command.md and the host wrapper
// sim2real/dxl_host.py.
static void cmdGoal(){
  waitForSerialInput();
  String input = DEBUG_SERIAL.readStringUntil('\n');
  input.trim();
  int colon = input.indexOf(':');
  String csv = (colon >= 0) ? input.substring(colon + 1) : input;

  char buf[256];
  csv.toCharArray(buf, sizeof(buf));
  char* token = strtok(buf, ",");
  int32_t target[SERVO_NUM] = {};
  int8_t  torque_control_flags[SERVO_NUM] = {};
  int32_t e_angles[SERVO_NUM] = {};
  int count = 0;
  while (token != NULL && count < SERVO_NUM) {
    target[count++] = atoi(token);
    token = strtok(NULL, ",");
  }
  if (count != SERVO_NUM) {
    DEBUG_SERIAL.print("ERR:expected ");
    DEBUG_SERIAL.print(SERVO_NUM);
    DEBUG_SERIAL.print(" ints, got ");
    DEBUG_SERIAL.println(count);
    return;
  }
  sweepRunGoalPosition(target, e_angles, torque_control_flags,
                        MOVING_TIME, millis());
  DEBUG_SERIAL.println("OK");
}

struct Command {
  const char* name;
  void (*handler)();
};

static const Command COMMANDS[] = {
  {"Teach",       cmdTeach},
  {"Start",       cmdStart},
  {"Delete",      cmdDelete},
  {"ls",          cmdLs},
  {"Relax",       cmdRelax},
  {"Fix",         cmdFix},
  {"Manual",      cmdManual},
  {"Static",      cmdStatic},
  {"Random",      cmdRandom},
  {"Unit",        cmdUnit},
  {"FingerDrive", cmdFingerDrive},
  {"Direction",   cmdDirection},
  {"DirectionAll",cmdDirectionAll},
  {"servo",       cmdServo},
  {"Show",        cmdShow},
  {"Goal",        cmdGoal},
};

void setup() {
  DEBUG_SERIAL.begin(115200);
  // while(!DEBUG_SERIAL);   // デバッグシリアルが接続されるまで待つ
  delay(1000);  // シリアルポートの安定化のために少し待つ
  // DISPLAY_SERIAL.begin(115200);
  dxl.begin(1000000);  // 1Mbps baud rate
  dxl.setPortProtocolVersion(DXL_PROTOCOL_VERSION);
  setMotorID();
  initCurrentLimit();
  // analogWriteFrequency(SERVO_PIN, 2000);  // 50Hz for servo control
  analogWriteResolution(12);  // 12-bit resolution for Teensy 4.1
  pinMode(SERVO_PIN, OUTPUT);

  initDXL();
  currentAndPositionCheck();
  initSD();
  randomSeed(analogRead(0));
  // DEBUG_SERIAL.println("COMMANDS:\nTeach: 教示モード\nStart: 連続運転モード\nStatic: 剛性試験モード");

  // デモ用: demo2.csv を Relax モーションで無限ループ再生
  fileName = "demo2.csv";
  uint8_t row_cnt = readAllData();
  DEBUG_SERIAL.print("DEMO: ");
  DEBUG_SERIAL.print(fileName);
  DEBUG_SERIAL.print(" rows=");
  DEBUG_SERIAL.println(row_cnt);
  while (1) {
    Start(row_cnt, MotionType::Relax);
  }
}

void loop() {
  if (!DEBUG_SERIAL.available()) return;

  String input = DEBUG_SERIAL.readStringUntil('\n');
  input.trim();

  for (const auto& cmd : COMMANDS) {
    if (input.equalsIgnoreCase(cmd.name)) {
      cmd.handler();
      return;
    }
  }
}

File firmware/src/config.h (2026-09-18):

#ifndef _CONFIG_H_
#define _CONFIG_H_

#include <Arduino.h>

#define READ_PERIOD 10 // 10ms 100Hz
#define TIMEOUT 10    //default communication timeout 10ms
#define NORMAL_SERVO 20
#define INFINITE_SERVO_NUM 2
#define SERVO_NUM (NORMAL_SERVO + INFINITE_SERVO_NUM)
#define MAX_ROWS 10          // 格納できる最大行数

const uint8_t FORCE_GAGE_PIN = A16;
const uint8_t ESYNC_PIN = A17;

#endif //_CONFIG_H_

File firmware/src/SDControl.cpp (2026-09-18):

#include "SDControl.h"
#include "DXLSetup.h"

SdFs sd;
FsFile dataFile;
String fileName = "sensor_data.csv";  // デフォルトのファイル名
bool isReading = false;

int32_t playback_positions[MAX_ROWS][SERVO_NUM] = {};

static String readFilenameFromSerial(const char* prompt){
  DEBUG_SERIAL.println(prompt);
  waitForSerialInput();
  String name = DEBUG_SERIAL.readStringUntil('\n');
  name.trim();
  return name;
}

static void ensureCsvExtension(String& name){
  if (!name.endsWith(".csv")) name += ".csv";
}

static bool confirmYN(const char* msg){
  DEBUG_SERIAL.println(msg);
  waitForSerialInput();
  String input = DEBUG_SERIAL.readStringUntil('\n');
  input.trim();
  return input.equalsIgnoreCase("y");
}

// SDカードのルート直下から .csv ファイルを列挙し、番号選択させる。
// キャンセルまたは候補なしの場合は空文字列を返す。
static String selectCsvByNumber(){
  constexpr uint8_t MAX_LIST = 32;
  String names[MAX_LIST];
  uint8_t count = 0;
  FsFile dir;
  FsFile entry;
  if (!dir.open("/", O_READ)) {
    DEBUG_SERIAL.println("ディレクトリを開けませんでした。");
    return String();
  }
  while (count < MAX_LIST && entry.openNext(&dir, O_READ)) {
    if (!entry.isDirectory()) {
      char nameBuf[64];
      entry.getName(nameBuf, sizeof(nameBuf));
      String n = String(nameBuf);
      if (n.endsWith(".csv") || n.endsWith(".CSV")) {
        names[count++] = n;
      }
    }
    entry.close();
  }
  dir.close();

  if (count == 0) {
    DEBUG_SERIAL.println("CSVファイルがありません。");
    return String();
  }

  while (true) {
    DEBUG_SERIAL.println("ファイルを選択してください:");
    for (uint8_t i = 0; i < count; i++) {
      DEBUG_SERIAL.print("  ");
      DEBUG_SERIAL.print(i + 1);
      DEBUG_SERIAL.print(": ");
      DEBUG_SERIAL.println(names[i]);
    }
    DEBUG_SERIAL.println("  c: キャンセル");
    waitForSerialInput();
    String input = DEBUG_SERIAL.readStringUntil('\n');
    input.trim();
    if (input.equalsIgnoreCase("c")) return String();
    int idx = input.toInt();
    if (idx >= 1 && idx <= (int)count) {
      return names[idx - 1];
    }
    DEBUG_SERIAL.println("無効な選択です。");
  }
}

static bool SDCheck(){
  if (!sd.card()->errorCode()) {
    DEBUG_SERIAL.println("SDカードは正常です。");
  } else {
    DEBUG_SERIAL.print("SDカードエラー: ");
    DEBUG_SERIAL.println(sd.card()->errorCode());
    isReading = false;
    return false;
  }

  if (!dataFile.open(fileName.c_str(), O_READ)) {
    DEBUG_SERIAL.println("ファイルのオープンに失敗しました。");
    DEBUG_SERIAL.print("SDカードエラー: ");
    DEBUG_SERIAL.println(sd.card()->errorCode());
    isReading = false;
    return false;
  }
  return true;
}

bool initSD(){
  isReading = true;
  DEBUG_SERIAL.println("Teensy 4.1 SDカードロガーを初期化中...");
  if (!sd.begin(SD_CONFIG)) {
    sd.initErrorHalt(&DEBUG_SERIAL);
    return false;
  }
  DEBUG_SERIAL.println("SDカード初期化完了");
  return true;
}

bool chooseFile(){
  String selected = selectCsvByNumber();
  if (selected.length() == 0) return false;
  fileName = selected;
  DEBUG_SERIAL.print("選択されたファイル: ");
  DEBUG_SERIAL.println(fileName);
  return true;
}

bool initFileName(){
  fileName = readFilenameFromSerial("ファイル名を入力してください（拡張子 .csv を含む）:");
  ensureCsvExtension(fileName);

  DEBUG_SERIAL.print("使用するファイル名: ");
  DEBUG_SERIAL.println(fileName);

  // ファイルが存在しない場合、ヘッダーを書き込む
  if (!sd.exists(fileName.c_str())) {
    dataFile = sd.open(fileName.c_str(), FILE_WRITE);
    if (dataFile) {
        String dataString = "";
        for (uint8_t i = 0; i < SERVO_NUM; i++)
        {
            dataString += String(i);
            if (i != SERVO_NUM-1) dataString += ",";
        }
      dataFile.println(dataString);
      dataFile.close();
      DEBUG_SERIAL.println("新しいファイルを作成し、ヘッダーを書き込みました。");
    } else {
      DEBUG_SERIAL.println("ファイルの作成に失敗しました。");
      return false;
    }
  } else {
    DEBUG_SERIAL.println("既存のファイルにデータを追加します。");
  }

  DEBUG_SERIAL.println("データ記録を開始します...");
  isReading = false;
  return true;
}

void writeArrayToSD(int16_t *array) {
  dataFile = sd.open(fileName.c_str(), FILE_WRITE);
  String dataArray = "";
  if (dataFile) {
    for (int i = 0; i < SERVO_NUM; i++) {
        dataArray += String(array[i]);
        if (i != SERVO_NUM-1) dataArray += ",";
    }
    dataFile.println(dataArray);
    dataFile.close();
    DEBUG_SERIAL.println("データをSDカードに書き込みました。");
  } else {
    DEBUG_SERIAL.println("ファイルのオープンに失敗しました。");
  }
}

// SDカードを読んでCSVデータの行数を返す
uint8_t readAllData() {
  DEBUG_SERIAL.println("データ読み取りを開始します...");
  isReading = true;
  uint8_t rowCount = 0;
  uint8_t columnCount = 0;


  if(!SDCheck()){
    return 0;
  }


  DEBUG_SERIAL.print("ファイルサイズ: ");
  DEBUG_SERIAL.println(dataFile.size());

  DEBUG_SERIAL.println("データを読み込んでいます...");
  char buffer[256];  // 1行の最大長を想定（必要に応じて調整）
  rowCount = 0;
  columnCount = 0;

  for (uint8_t i = 0; i < MAX_ROWS; i++)
  {
    for (uint8_t j = 0; j < SERVO_NUM; j++)
    {
      playback_positions[i][j] = 0;
    }

  }
  // 先頭行（列番号）をスキップ
  String header = dataFile.readStringUntil('\n');

  while (dataFile.available() && rowCount < MAX_ROWS) {
    if (dataFile.fgets(buffer, sizeof(buffer)) > 0) {
      char* token = strtok(buffer, ",");
      int col = 0;
      while (token != NULL && col < SERVO_NUM) {
        playback_positions[rowCount][col] = atoi(token);
        token = strtok(NULL, ",");
        col++;
      }
      if (col > columnCount) columnCount = col;
      rowCount++;
    }

    // 進捗状況を表示（10行ごと）
    if (rowCount % 10 == 0) {
      DEBUG_SERIAL.print("読み込み中... 行数: ");
      DEBUG_SERIAL.println(rowCount);
    }
  }

  dataFile.close();

  DEBUG_SERIAL.println("---");
  DEBUG_SERIAL.print("読み込んだ行数: ");
  DEBUG_SERIAL.println(rowCount);
  DEBUG_SERIAL.print("列数: ");
  DEBUG_SERIAL.println(columnCount);
  DEBUG_SERIAL.println("データ読み取りが完了しました。");

  isReading = false;
  return rowCount;
}

void listFiles() {
  DEBUG_SERIAL.println("SDカード内のファイル一覧:");
  sd.ls(LS_R | LS_DATE | LS_SIZE);
  DEBUG_SERIAL.println();
}

void deleteFile() {
  String selected = selectCsvByNumber();
  if (selected.length() == 0) {
    DEBUG_SERIAL.println("キャンセルしました。");
    return;
  }
  DEBUG_SERIAL.print("削除するファイル: ");
  DEBUG_SERIAL.println(selected);
  if (!confirmYN("本当に削除しますか？ y/n")) {
    DEBUG_SERIAL.println("キャンセルしました。");
    return;
  }
  if (sd.remove(selected.c_str())) {
    DEBUG_SERIAL.println("ファイルを削除しました。");
  } else {
    DEBUG_SERIAL.println("ファイルの削除に失敗しました。");
  }
}

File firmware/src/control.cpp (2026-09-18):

#include "control.h"

// Dynamixelモーターのモード設定関数
void dxlModeSetup(uint8_t mode){
    // Turn off torque when configuring items in EEPROM area
    for (uint8_t i = 0; i < SERVO_NUM; i++)
    {
        dxl.torqueOff(i);
    }
    // Set Operating Mode
    for (uint8_t i = 0; i < SERVO_NUM; i++)
    {
        sw_op_mode.data[i].mode = mode;
    }
    sw_op_mode.markChanged();
    sw_op_mode.write("Operating Mode");
}

void initGoalCurrent(int8_t *torque_control_flags){
    for (uint8_t i = 0; i < SERVO_NUM; i++)
    {
        if (torque_control_flags[i] != 0)
        {
            sw_current_velocity.data[i].goal_current = 0;
            sw_current_velocity.data[i].goal_velocity = 0;
        }
        // sw_position.data[i].goal_position = 0;
    }
    sw_current_velocity.markChanged();
}

void computeEAngles(int32_t *e_angles, const int32_t *goal_row){
    for (uint8_t ID = 0; ID < SERVO_NUM; ID++)
    {
        e_angles[ID] = goal_row[ID] - muscles[ID]->getPosition();
    }
}

static void captureAndTorqueOn(int32_t *now_angle){
    for (uint8_t i = 0; i < SERVO_NUM; i++) now_angle[i] = muscles[i]->getPosition();
    for (uint8_t i = 0; i < SERVO_NUM; i++) dxl.torqueOn(i);
}

// flag > 0: モーター正転で筋を緊張させる。
// muscles[i]->getForwardLimit() は緊張方向の位置上限。
static void rampTension(uint8_t i, float chunk, float cnt){
    if (muscles[i]->getPosition() > muscles[i]->getForwardLimit()){
        dxl.torqueOff(i);
        return;
    }
    const uint16_t lim = muscles[i]->getCurrentLimit();
    if (muscles[i]->getCurrent() < lim
        && sw_current_velocity.data[i].goal_current < lim){
        sw_current_velocity.data[i].goal_current += lim * chunk * cnt;
    } else {
        sw_current_velocity.data[i].goal_current = lim;
    }
}

// flag < 0: モーター逆転で筋を弛緩させる。
// muscles[i]->getBackwardLimit() は弛緩方向の位置下限。
// Goal Current(102) は符号付き int16_t で負値が逆転を生む。Current Limit(38) は
// 符号なし uint16_t の magnitude で |goal_current| <= current_limit。
// directionTest(Motor 3, DriveMode bit0=0 Normal) により，+電流=正転/位置増，
// −電流=逆転/位置減 を実機確認済。したがって弛緩には負値を書き込む必要がある。
// 前提: 本ループが扱う各サーボの DriveMode bit0 = Normal であること。
// Reverse に設定されたサーボが混在する場合、当該サーボのみ弛緩方向が反転する。
static void rampRelaxation(uint8_t i, float chunk, float cnt){
    if (muscles[i]->getPosition() < muscles[i]->getBackwardLimit()){
        dxl.torqueOff(i);
        return;
    }
    const uint16_t lim = muscles[i]->getCurrentLimit();
    const int16_t target = -static_cast<int16_t>(lim);
    if (muscles[i]->getCurrent() > target
        && sw_current_velocity.data[i].goal_current > target){
        sw_current_velocity.data[i].goal_current -= lim * chunk * cnt;
    } else {
        sw_current_velocity.data[i].goal_current = target;
    }
}

// 位置制御の場合は目標位置を徐々に上昇させる
static void rampPosition(uint8_t i, const int32_t *goal_pos, const int32_t *e_angles,
                         const int32_t *now_angle, float chunk, float cnt){
    if (e_angles[i] > 0 && sw_position.data[i].goal_position < goal_pos[i]){
        sw_position.data[i].goal_position = float(now_angle[i]) + (float(e_angles[i]) * chunk * float(cnt));
    } else if (e_angles[i] <= 0 && sw_position.data[i].goal_position > goal_pos[i]){
        sw_position.data[i].goal_position = float(now_angle[i]) + (float(e_angles[i]) * chunk * float(cnt) * 1.5);
    } else {
        sw_position.data[i].goal_position = goal_pos[i];
    }
}

bool sweepRunGoalPosition(const int32_t *goal_pos, int32_t *e_angles, int8_t *torque_control_flags, uint16_t time, uint32_t start) {
    int32_t now_angle[SERVO_NUM] = {};
    captureAndTorqueOn(now_angle);

    const float sampling_period = READ_PERIOD;
    const float period_offset = 40.0;
    // 電流値をスイープさせるためのチャンクサイズ
    const float chunk = (sampling_period + period_offset) / (time * 1000);
    float cnt = 1.0;

    currentAndPositionCheck();
    initGoalCurrent(torque_control_flags);
    while (time * 1000 > (millis() - start)){
        for (uint8_t i = 0; i < SERVO_NUM; i++){
            if      (torque_control_flags[i] > 0) rampTension(i, chunk, cnt);
            else if (torque_control_flags[i] < 0) rampRelaxation(i, chunk, cnt);
            else                                  rampPosition(i, goal_pos, e_angles, now_angle, chunk, cnt);
        }
        sw_position.markChanged();
        sw_current_velocity.markChanged();
        if (!sw_position.write("Position")) return false;
        sw_current_velocity.write("Current and Velocity");
        cnt++;
        delay(sampling_period);
        currentAndPositionCheck();
        DEBUG_SERIAL.println(getCurrentAndPositionArray(start));
    }
    return true;
}

/**
 * @brief
 *
 * @param start 開始時刻
 */
String getCurrentAndPositionArray(uint32_t start){
    String sendStringData = "";
    unsigned long time = millis();
    sendStringData += String(time - start) + ",";
    for (uint8_t i = 0; i < SERVO_NUM; i++)
    {
        sendStringData += String(muscles[i]->getCurrent()) + "," + String(muscles[i]->getPosition()) + ",";
    }
    return sendStringData;
}


/**
 * @brief 電流と角度を定期実行する関数
 *
 */
void currentAndPositionCheck (){
    for (uint8_t i=0; i < SERVO_NUM; i++){
        muscles[i]->checkCurrent();
    }
    for (uint8_t i=0; i < SERVO_NUM; i++){
        muscles[i]->checkPosition();
    }
}

void torqueOnExceptEndless(bool useEndlessMecha){
    for (uint8_t i = 0; i < SERVO_NUM; i++){
        if (!useEndlessMecha && muscles[i]->isEndlessWinding()) continue;
        dxl.torqueOn(i);
    }
}

void servoStop(){
    for (uint8_t i = 0; i < SERVO_NUM; i++)
    {
        dxl.torqueOff(i);
    }
}

bool fix(){
      dxlModeSetup(OP_CURRENT);
      torqueOnExceptEndless(false);
      for (uint8_t i = 0; i < SERVO_NUM; i++)
      {
        sw_current_velocity.data[i].goal_current = 20;
      }
      sw_current_velocity.markChanged();
      return sw_current_velocity.write("Current and Velocity");
}

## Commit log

2026-09-18 Initial release: anthropomimetic soft robotic forearm with articulated carpal bones
    Open-hardware data for the paper "Anthropomimetic Soft Robotic Forearm with
    Independently Articulated Carpal Bones Enabling Human-Like Adaptive Stiffness
    Modulability".
    - cad/ 75 parts (STEP, F3D): bones, TFCC, motor tower, assembly and experimental jigs
    - stl/ print-ready STL for the same 75 parts
    - firmware/ Teensy 4.1 / Dynamixel muscle control (PlatformIO)
    - analysis/ wrist stiffness ellipse and intra-carpal motion analysis with measured data
    - media/ supplementary video
    [0804_grasp_cylinder.csv, FingerWrist_001.csv, FingerWrist_002.csv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]
2026-09-18 fix: correct licensing for BodyParts3D-derived bone models
    The bone geometry is derived from BodyParts3D (Life Science Integrated
    Database Center), which is distributed under CC BY-SA 2.1 JP. The previous
    single CC BY 4.0 declaration was therefore incorrect for those files.
    Adopt the dual-license structure used in anthropomimetic-foot-joint-structure:
    - CC BY-SA 2.1 JP: 49 anatomical bone parts, including the fused proximal row
    parts derived from them by joining in CAD
    - CC BY 4.0: 26 original parts (geometric ellipsoidal skeleton, motor tower,
    assembly and experimental jigs, TFCC disc), firmware, analysis, media
    Also fix the stl/ description in the repository structure block, which l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
2026-09-18 fix: place all bone_* parts under CC BY-SA 2.1 JP
    The geometric ellipsoidal skeleton parts (bone_ellipsoidal_carpal_*) also
    incorporate BodyParts3D-derived geometry, so the previous exclusion was wrong.
    Apply the share-alike license to all 52 bone_* parts without exception.
    The split is now a single clean rule:
    - CC BY-SA 2.1 JP: cad/bone_*, stl/bone_* (52 parts)
    - CC BY 4.0: everything else (23 parts, firmware, analysis, media)
2026-09-21 add servo horn data and skin mold datas of distal phalanx with nail
    [Skin_mold_index_with_nail.step, Skin_mold_middle_with_nail.f3d, Skin_mold_middle_with_nail.step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]
2026-09-24 Split multi-body CAD into bone/mold/tower parts and license molds as CC BY-SA
    - Split the skin mold assemblies into individual parts:
    bone_*_distal_phalanx+nail (5), mold_* (23)
    - Rename xl330_servo_horn to tower_motor_pulley
    - Add STL for all new parts (cad/stl now 1:1, 104 parts)
    - License: mold_* are shaped around BodyParts3D-derived distal phalanges,
    so they follow bone_* under CC BY-SA 2.1 JP
    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
    [Skin_mold_index_with_nail.step, Skin_mold_middle_with_nail.f3d, Skin_mold_middle_with_nail.step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]
2026-09-24 Rename bone_*_distal_phalanx+nail to bone_*_distal_phalanx_with_nail
    Avoid "+" in file names, which some tools decode as a space in URLs.
    Correction to 3617a47: tower_motor_pulley was newly remodeled, not renamed
    from xl330_servo_horn. The old servo horn files were removed and the pulley
    was added as a new part.
    [bone_index_distal_phalanx_with_nail.f3d, bone_index_distal_phalanx_with_nail.step, bone_index_distal_phalanx_with_nail.stl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]
2026-09-25 outer fix data of index and middle
    [mold_index_outer_fix.f3d, mold_index_outer_fix.step, mold_middle_outer_fix.f3d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]
